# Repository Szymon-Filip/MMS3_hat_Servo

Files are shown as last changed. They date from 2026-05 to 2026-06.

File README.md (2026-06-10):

# Hat 4-kanałowy sterownik serw

## Sekcja 1: Dokumentacja Hat'a

### Krótki opis projektu
Hat to 4-kanałowy sterownik serw, bazujący na  generatorze PWM **PCA9685PW** (komunikacja I2C). Zasialnie serw jest z XT60

### Zgodność ze standardem ChainBus

* ✅ Używa złącza ChainBus, nie zmienia jego miejsca ani pinoutu.
* ✅ Używa wyłącznie interfejsów I2C, SPI lub UART i nie inicjuje samodzielnie nowych transmisji (Nie jest master'em I2C albo SPI).
* ✅ Spełnia wymagania mechaniczne standardu (wymiary PCB, rozstaw otworów).
* ✅ Pobiera maksymalny prąd zgodny z ilością na jednego hat'a
* ✅ Obsługuje napięcie wejściowe BRD_VIN do wartości 48V.

### Komunikacja i adresowanie

#### Adresacja I2C
Komunikacja z PCA9685PW odbywa się za pomocą magistrali I2C. Wszystkie linie adresowe układu PCA9685PW (A0, A1, A2, A3, A4, A5) są podłączone do napięcia 5V.

| Układ (IC) | Funkcja | Adres I2C (7-bit) |
| :--- | :--- | :---: |
| **PCA9685PW** | 16-kanałowy generator PWM 12-bit | `1111111b` (0x7F) |

---

### Przypisanie kanałów generatora PCA9685

Układ PCA9685 steruje bezpośrednio czterema wyjściami serw oraz dwoma debug diodami LED:

| Wyjście PCA9685 | Powiązany element | Typ złącza  | Opis |
| :---: | :--- | :--- | :--- |
| **LED0** | Servo 1 | **J10** | Kanał sterujący serwomechanizmu 1 |
| **LED1** | Servo 2 | **J9** | Kanał sterujący serwomechanizmu 2 |
| **LED2** | Servo 3 | **J8** | Kanał sterujący serwomechanizmu 3 |
| **LED3** | Servo 4 | **J7** | Kanał sterujący serwomechanizmu 4 |
| **LED14** | Debug LED | *Na płycie* | Dioda LED do debugowania |
| **LED15** | Debug LED | *Na płycie* | Dioda LED do debugowania |

---

### Pinout złączy serwomechanizmów (J7 – J10)

Każde złącze wyjściowe (J7, J8, J9, J10) posiada 3 piny w następującym układzie:

| Pin | Nazwa sygnału | Poziom napięcia | Opis |
| :---- | :--- | :--- | :--- |
| **1** | `GND` | 0 V | Wspólna masa układu |
| **2** | `SERVO` (PWM) | 5 V | Sygnał sterujący PWM z układu PCA9685 |
| **3** | `VCC` | `BRD_VIN` (z XT60) | Napięcie zasilające silnik serwomechanizmu |

> **⚠️ UWAGA DOTYCZĄCA BEZPIECZEŃSTWA (PINOUT):**
> Układ wyprowadzeń złączy na tym module to **[1: GND, 2: Sygnał, 3: VCC]**. Jest on odmienny od klasycznego modelarskiego standardu wtyczek serwomechanizmów (gdzie pin zasilania VCC zazwyczaj znajduje się w środku wtyku).
>
> Przed podłączeniem serwomechanizmu należy bezwzględnie zweryfikować kolejność przewodów w wiązce serwa. Błędne podłączenie może skutkować uszkodzeniem serwa lub obwodów zasilania modułu.

---

### Szczegółowy opis techniczny

#### Zasilanie serwomechanizmów (`VCC`)
Prąd zasilania serwomechanizmów nie obciąża wewnętrznych linii zasilających magistrali ChainBus. Napięcie doprowadzane jest bezpośrednio ze złącza wysokoprądowego **XT60** na pin 3 każdego złącza serwa. Zasilanie z XT-60 od razu idzie na szyne VIN ChainBus'a. Jeśli potrzebujesz zasilić serwa innym napięciem niż takim samym jak VIN ChainBus'a to odlutuj D1 (tą diode po lewej stronie do której idzie taka duża ścieżka)

#### Sterowanie sygnałem PWM
PWM jest na 5V, ale szyna I2C na 3V3 więc wszystko śmiga jak powinno

---

### Gotowe arkusze hierarchiczne
W projekcie wydzielono i zastosowano następujące arkusze hierarchiczne:
* **Servo_controller** – Schemat generatora PWM PCA9685 z konwerterem I2C 3v3 <-> 5V i zworkami do wybierania adresu I2C

---

## Sekcja 2: Specyfikacja standardu ChainBus

### Architektura i łączenie modułów
Standard ChainBus umożliwia modułowe łączenie hatów. Na jednym MMS3 można zamontować pionowo **do 8 hat'ów**. Połączenie realizowane jest poprzez wpięcie złącza męskiego kolejnego hat'a w złącze żeńskie poprzedniego.

### Komunikacja i sterowanie
Magistrala ChainBus jest w pełni cyfrowa. Płyta główna nie steruje bezpośrednio sygnałami ogólnego przeznaczenia (GPIO) na poszczególnych hat'ach. Wszelkie operacje (np. generowanie sygnałów PWM, obsługa diod) muszą być realizowane przez dedykowane układy scalone komunikujące się przez interfejsy systemowe.

Wybór aktywnego modułu realizowany jest przez układ przełącznika magistrali (bus switch) na płycie głównej. Dzięki temu linie I2C, SPI i UART są niezależne dla każdego hat'a (brak konfliktów adresów I2C między różnymi hatami).
* **Identyfikacja:** Każdy moduł powinien posiadać pamięć EEPROM na magistrali I2C w celu identyfikacji płyty przez system - układ M24C64-W skonfigurowany na adres `1010000` przy liniach adresowych A0, A1, A2 zwartych do masy.

### Zasilanie
Złącze ChainBus dostarcza następujące linie zasilania:

| Magistrala zasilania | Napięcie znamionowe | Maksymalny prąd (łączny dla 8 hatów) | Szacowany prąd na jeden hat |
| :--- | :---: | :---: | :---: |
| **5V** | 5.0 V | 1.0 A | 125 mA |
| **12V stby** | 12.0 V | 0.5 A | 65 mA |
| **BRD_VIN** | 12.0 V – 48.0 V | 1.5 A | 185 mA |

*   W przypadku zapotrzebowania na wyższą moc (jak w przypadku tego modułu sterowania serwami), stosuje się dodatkowe złącze zasilania XT60 (obciążalność do ok. 60 A).

---

## Sekcja 3: Licencja, linki i tagi

### Licencjonowanie projektu

*   **PCB:** [CERN-OHL-W](https://ohwr.org/project/cernohl/wikis/Documents/CERN-OHL-version-2) - Umożliwia modyfikacje i sprzedaż pod warunkiem zachowania informacji o oryginalnym autorze. Zmiany muszą być open source.
*   **Software:** [MIT License](https://opensource.org/licenses/MIT) - Umożliwia modyfikacje i sprzedaż komercyjną pod warunkiem zachowania informacji o autorze (zmiany nie muszą być udostępniane jako open source).

### Tagi projektu
#chainbus #MMS3 #ModuCard

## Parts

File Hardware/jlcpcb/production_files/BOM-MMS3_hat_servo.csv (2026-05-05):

Comment | Designator | Footprint | LCSC | Quantity
100nF | C1,C2,C30 | C_0603 | C14663 | 3
10kΩ | R12,R19,R2,R20,R21,R22,R28,R29,R3,R30,R31,R32,R33,R6,R7,R8,R9 | R_0402 | C25744 | 17
10uF | C16,C18,C29 | C_0603 | C19702 | 3
330Ω | R1 | R_0402 | C25104 | 1
510Ω | R10,R11 | R_0402 | C25123 | 2
AMS1117 | U4 | SOT-223-3_L6.5-W3.4-P2.30-LS7.0-BR | C6186 | 1
AO3400A | Q4,Q5 | Q_SOT-23 | C20917 | 2
M24C64 | U2 | SOIC-8_L5.0-W4.0-P1.27-LS6.0-BL | C79988 | 1
M7 | D1 | D_SMA | C95872 | 1
PCA9685PW,118 | U1 | TSSOP-28_L9.7-W4.4-P0.65-LS6.4-TL | C2678753 | 1
Red | D5,D6,D7 | D_0603 | C2286 | 3
SN74CB3Q3245PWR | U3 | TSSOP-20_L6.5-W4.4-P0.65-LS6.4-BL | C470961 | 1
Conn_01x03 | J10 | JST_XH_S3B-XH-A_1x03_P2.50mm_Horizontal |  | 1
Conn_01x03 | J7 | JST_XH_S3B-XH-A_1x03_P2.50mm_Horizontal |  | 1
Chainbus Out | J2 | PinSocket_2x16_P2.54mm_Vertical_SMD |  | 1
Conn_01x03 | J9 | JST_XH_S3B-XH-A_1x03_P2.50mm_Horizontal |  | 1
Conn_01x04_Pin | J3 | PinHeader_1x04_P2.54mm_Vertical |  | 1
Conn_01x03 | J8 | JST_XH_S3B-XH-A_1x03_P2.50mm_Horizontal |  | 1
Chainbus in | J1 | PinHeader_2x16_P2.54mm_Vertical_SMD |  | 1

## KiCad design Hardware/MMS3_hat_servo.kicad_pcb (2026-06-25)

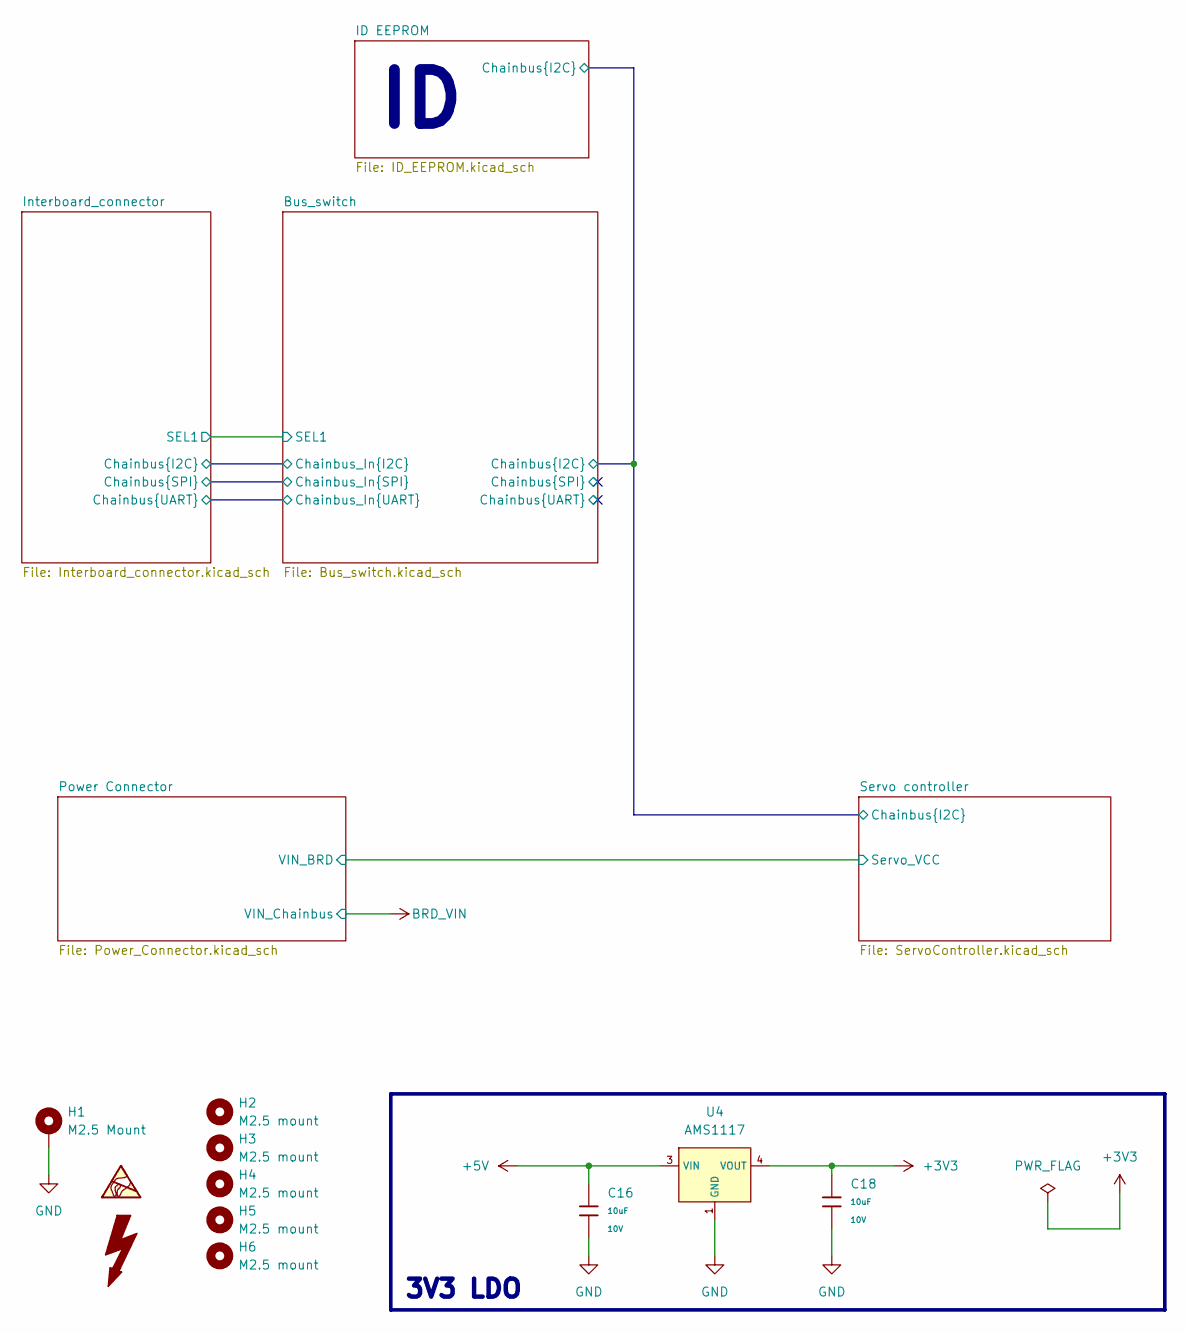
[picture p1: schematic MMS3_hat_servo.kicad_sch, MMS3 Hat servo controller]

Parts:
C16, C18: 10uF; C_0603; Voltage Rated 10V; Tolerance ±10%; Part CL10A106KP8NNNC; LCSC C19702
H1: M2.5 Mount; MountingHole_2.7mm_M2.5_DIN965_Pad_TopOnly
H2, H3, H4, H5, H6: M2.5 mount; MountingHole_2.7mm_M2.5
U4: AMS1117; SOT-223-3_L6.5-W3.4-P2.30-LS7.0-BR; Output Voltage 3.3V; Dropout Voltage 1.3V@(800mA); Part AMS1117-3.3; LCSC C6186

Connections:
+3V3: C18.1, U4.2 (VOUT), U4.4 (VOUT); also elsewhere on the board
+5V: C16.1, U4.3 (VIN); also elsewhere on the board
GND: C16.2, C18.2, H1.1 (1_1), U4.1 (GND); also elsewhere on the board

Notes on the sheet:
3V3 LDO

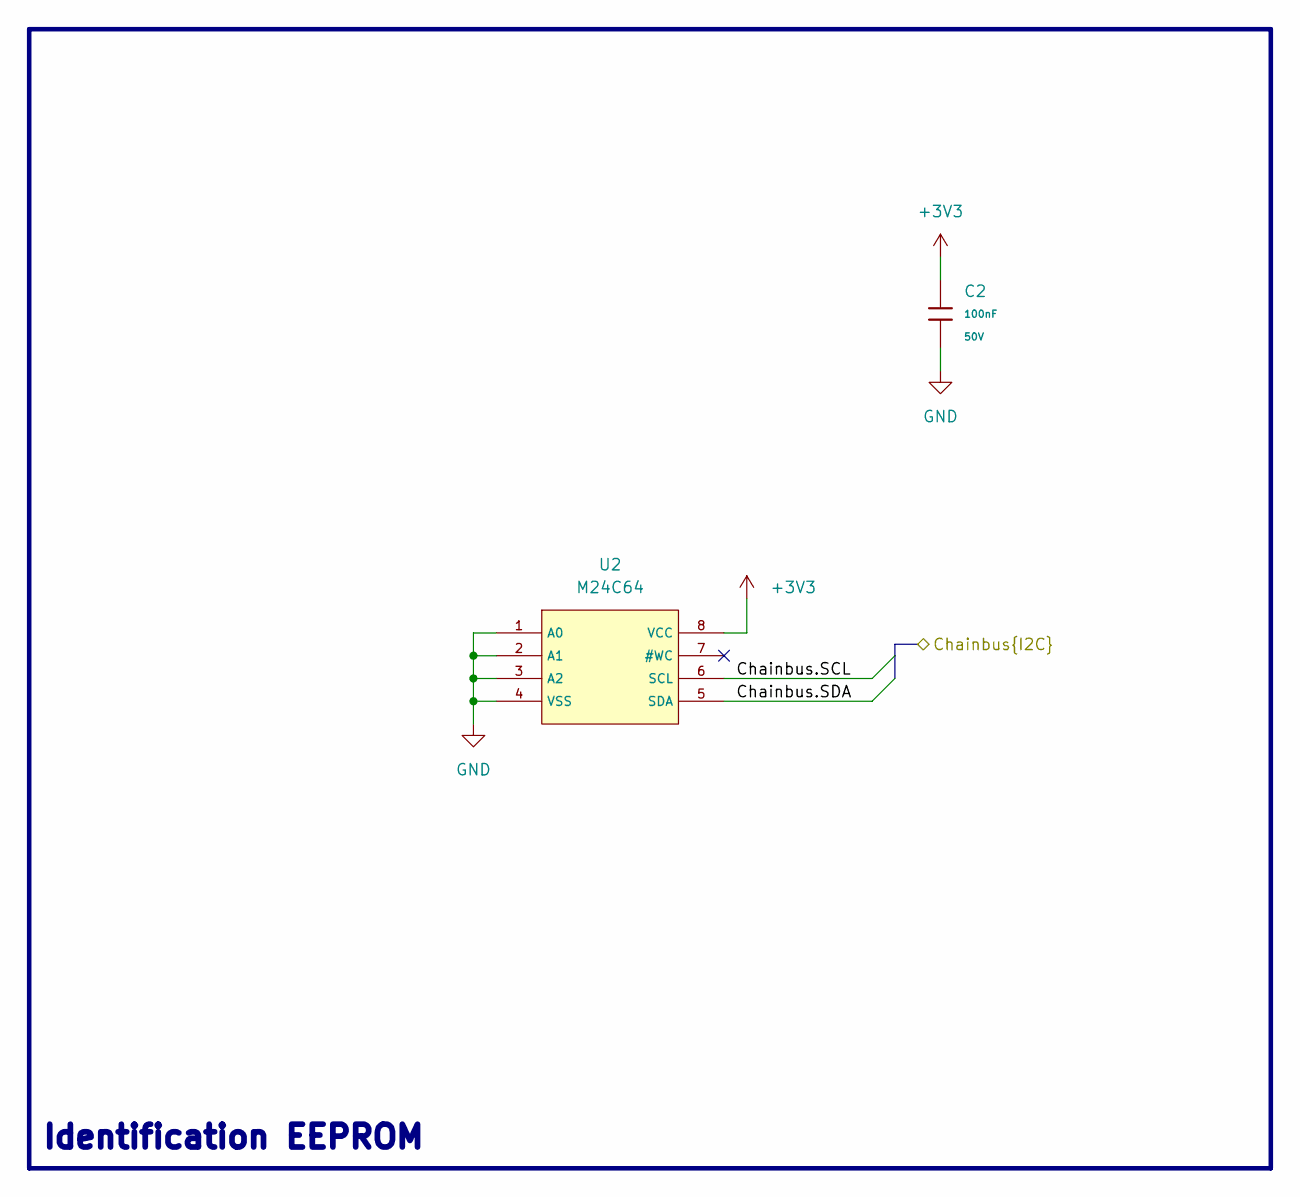
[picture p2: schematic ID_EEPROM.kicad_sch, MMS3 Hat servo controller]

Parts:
C2: 100nF; C_0603; Voltage Rated 50V; Tolerance ±10%; Part CC0603KRX7R9BB104; LCSC C14663
U2: M24C64; SOIC-8_L5.0-W4.0-P1.27-LS6.0-BL; Supply Voltage 1.8V~5.5V; Part M24C64-RMN6TP; LCSC C79988

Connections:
+3V3: C2.1, U2.8 (VCC); also elsewhere on the board
/Bus_switch/Chainbus.SCL: U2.6 (SCL); also elsewhere on the board
/Bus_switch/Chainbus.SDA: U2.5 (SDA); also elsewhere on the board
GND: C2.2, U2.1 (A0), U2.2 (A1), U2.3 (A2), U2.4 (VSS); also elsewhere on the board

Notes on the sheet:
Identification EEPROM

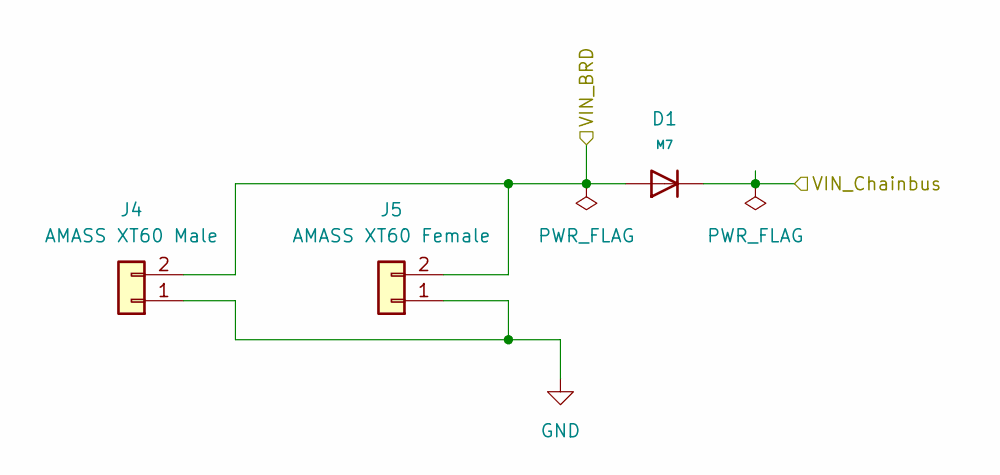
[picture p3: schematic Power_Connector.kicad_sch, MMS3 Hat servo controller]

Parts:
D1: M7; D_SMA; Forward Voltage (Vf@If) 1.1V@1A; Reverse Voltage (Vr) 1kV; Part M7; LCSC C95872
J4: AMASS XT60 Male; AMASS_XT60PW-M_1x02_P7.20mm_Horizontal; LCSC C98732
J5: AMASS XT60 Female; AMASS_XT60PW-F_1x02_P7.20mm_Horizontal; LCSC C428722

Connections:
/Power Connector/VIN_BRD: D1.2, J4.2, J5.2; also elsewhere on the board
BRD_VIN: D1.1; also elsewhere on the board
GND: J4.1, J5.1; also elsewhere on the board

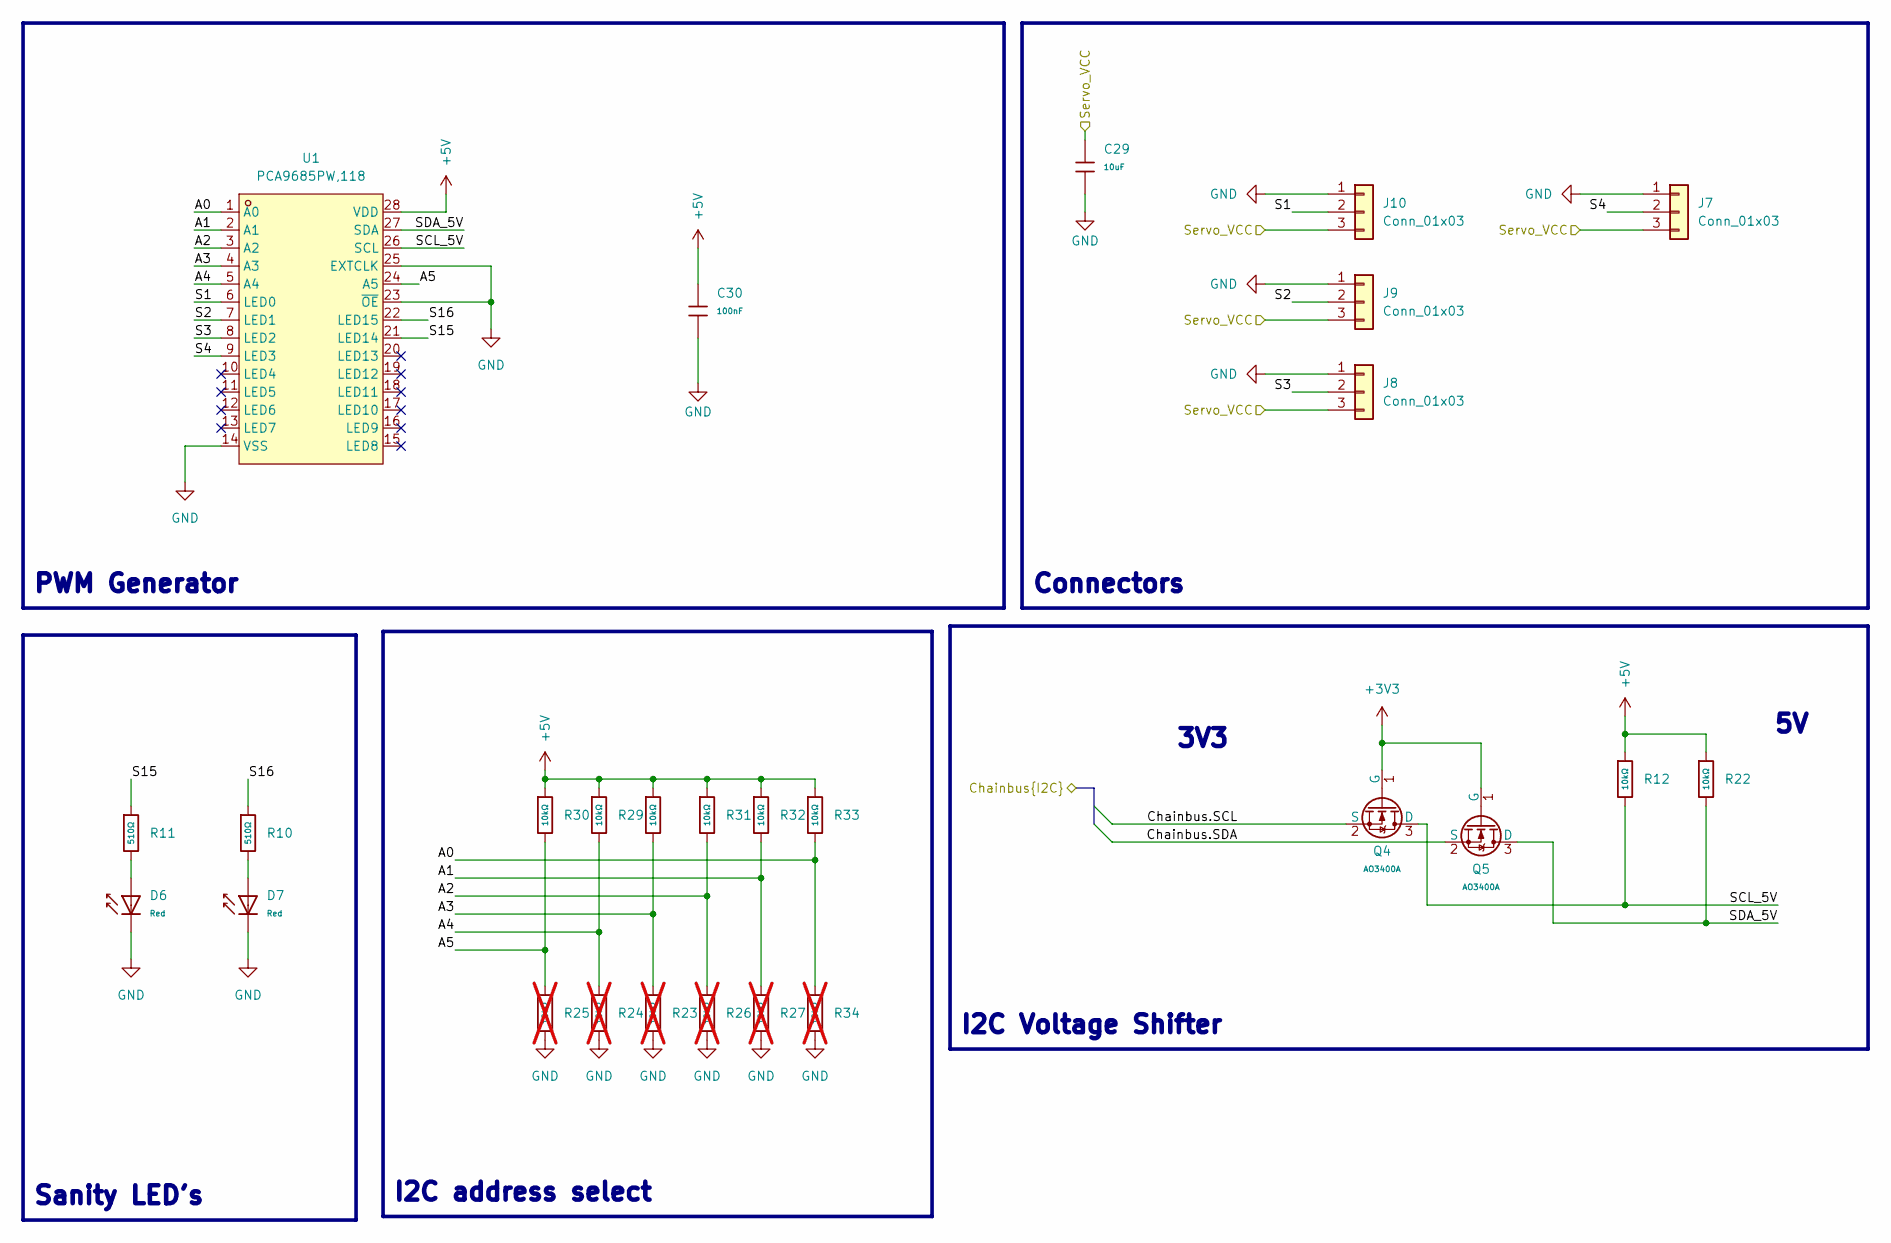
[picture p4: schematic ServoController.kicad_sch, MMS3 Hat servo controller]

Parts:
C29: 10uF; C_0603; Voltage Rated 10V; Tolerance ±10%; Part CL10A106KP8NNNC; LCSC C19702
C30: 100nF; C_0603; Voltage Rated 50V; Tolerance ±10%; Part CC0603KRX7R9BB104; LCSC C14663
D6, D7: Red; D_0603; Part KT-0603R; LCSC C2286
J7, J8, J9, J10: Conn_01x03; JST_XH_S3B-XH-A_1x03_P2.50mm_Horizontal
Q4, Q5: AO3400A; Q_SOT-23; Part AO3400A; LCSC C20917
R10, R11: 510Ω; R_0402; Overload Voltage (Max) 50V; Tolerance ±1%; Part 0402WGF5100TCE; LCSC C25123
R12, R22, R28, R29, R30, R31, R32, R33: 10kΩ; R_0402; Overload Voltage (Max) 50V; Tolerance ±1%; Part 0402WGF1002TCE; LCSC C25744
R23, R24, R25, R26, R27, R34: 10kΩ; R_0402; Overload Voltage (Max) 50V; Tolerance ±1%; Part 0402WGF1002TCE; LCSC C25744; not fitted
U1: PCA9685PW,118; TSSOP-28_L9.7-W4.4-P0.65-LS6.4-TL; MPN PCA9685PW,118; LCSC Part C2678753

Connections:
+3V3: Q4.1 (G), Q5.1 (G); also elsewhere on the board
+5V: C30.1, R12.1, R22.1, R28.1, R29.1, R30.1, R31.1, R32.1, R33.1, U1.28 (VDD); also elsewhere on the board
/Bus_switch/Chainbus.SCL: Q4.2 (S); also elsewhere on the board
/Bus_switch/Chainbus.SDA: Q5.2 (S); also elsewhere on the board
/Power Connector/VIN_BRD: C29.1, J7.3, J8.3, J9.3, J10.3; also elsewhere on the board
/Servo controller/A0: R33.2, R34.1, U1.1 (A0)
/Servo controller/A1: R27.1, R32.2, U1.2 (A1)
/Servo controller/A2: R26.1, R31.2, U1.3 (A2)
/Servo controller/A3: R23.1, R28.2, U1.4 (A3)
/Servo controller/A4: R24.1, R29.2, U1.5 (A4)
/Servo controller/A5: R25.1, R30.2, U1.24 (A5)
/Servo controller/S1: J10.2, U1.6 (LED0)
/Servo controller/S2: J9.2, U1.7 (LED1)
/Servo controller/S3: J8.2, U1.8 (LED2)
/Servo controller/S4: J7.2, U1.9 (LED3)
/Servo controller/S15: R11.1, U1.21 (LED14)
/Servo controller/S16: R10.1, U1.22 (LED15)
/Servo controller/SCL_5V: Q4.3 (D), R12.2, U1.26 (SCL)
/Servo controller/SDA_5V: Q5.3 (D), R22.2, U1.27 (SDA)
GND: C29.2, C30.2, D6.1, D7.1, J7.1, J8.1, J9.1, J10.1, R23.2, R24.2, R25.2, R26.2, R27.2, R34.2, U1.14 (VSS), U1.23 (~OE), U1.25 (EXTCLK); also elsewhere on the board
unnamed: D6.2, R11.2
unnamed: D7.2, R10.2

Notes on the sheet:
Sanity LED's
Connectors
I2C Voltage Shifter
PWM Generator
3V3
I2C address select

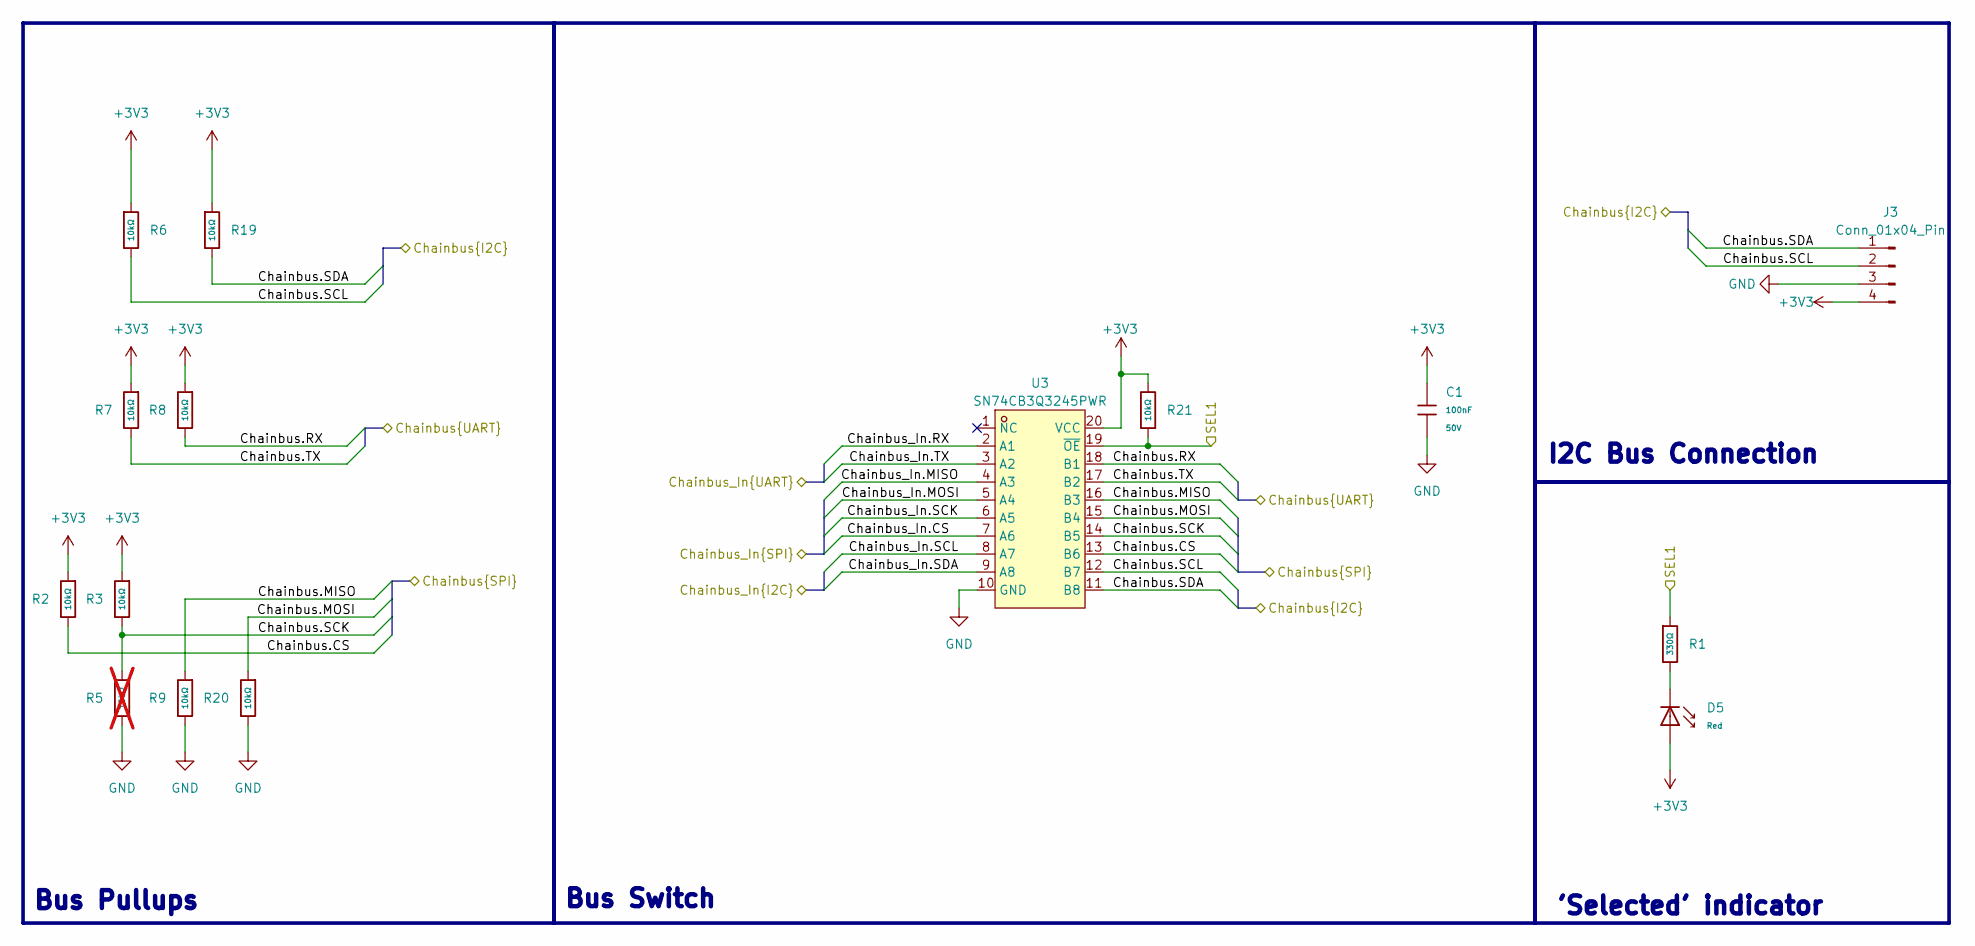
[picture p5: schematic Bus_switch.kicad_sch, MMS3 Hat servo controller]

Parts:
C1: 100nF; C_0603; Voltage Rated 50V; Tolerance ±10%; Part CC0603KRX7R9BB104; LCSC C14663
D5: Red; D_0603; Part KT-0603R; LCSC C2286
J3: Conn_01x04_Pin; PinHeader_1x04_P2.54mm_Vertical
R1: 330Ω; R_0402; Overload Voltage (Max) 50V; Tolerance ±1%; Part 0402WGF3300TCE; LCSC C25104
R2, R3, R6, R7, R8, R9, R19, R20, R21: 10kΩ; R_0402; Overload Voltage (Max) 50V; Tolerance ±1%; Part 0402WGF1002TCE; LCSC C25744
R5: 10kΩ; R_0402; Overload Voltage (Max) 50V; Tolerance ±1%; Part 0402WGF1002TCE; LCSC C25744; not fitted
U3: SN74CB3Q3245PWR; TSSOP-20_L6.5-W4.4-P0.65-LS6.4-BL; MPN SN74CB3Q3245PWR; LCSC Part C470961

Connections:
+3V3: C1.1, D5.2, J3.4, R2.1, R3.1, R6.1, R7.1, R8.1, R19.1, R21.2, U3.20 (VCC); also elsewhere on the board
/Bus_switch/Chainbus.CS: R2.2, U3.13 (B6)
/Bus_switch/Chainbus.MISO: R9.1, U3.16 (B3)
/Bus_switch/Chainbus.MOSI: R20.1, U3.15 (B4)
/Bus_switch/Chainbus.RX: R8.2, U3.18 (B1)
/Bus_switch/Chainbus.SCK: R3.2, R5.1, U3.14 (B5)
/Bus_switch/Chainbus.SCL: J3.2, R6.2, U3.12 (B7); also elsewhere on the board
/Bus_switch/Chainbus.SDA: J3.1, R19.2, U3.11 (B8); also elsewhere on the board
/Bus_switch/Chainbus.TX: R7.2, U3.17 (B2)
/Bus_switch/Chainbus_In.CS: U3.7 (A6); also elsewhere on the board
/Bus_switch/Chainbus_In.MISO: U3.4 (A3); also elsewhere on the board
/Bus_switch/Chainbus_In.MOSI: U3.5 (A4); also elsewhere on the board
/Bus_switch/Chainbus_In.RX: U3.2 (A1); also elsewhere on the board
/Bus_switch/Chainbus_In.SCK: U3.6 (A5); also elsewhere on the board
/Bus_switch/Chainbus_In.SCL: U3.8 (A7); also elsewhere on the board
/Bus_switch/Chainbus_In.SDA: U3.9 (A8); also elsewhere on the board
/Bus_switch/Chainbus_In.TX: U3.3 (A2); also elsewhere on the board
/Bus_switch/SEL1: R1.1, R21.1, U3.19 (~OE); also elsewhere on the board
GND: C1.2, J3.3, R5.2, R9.2, R20.2, U3.10 (GND); also elsewhere on the board
unnamed: D5.1, R1.2

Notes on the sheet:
'Selected' indicator
Bus Switch
I2C Bus Connection
Bus Pullups

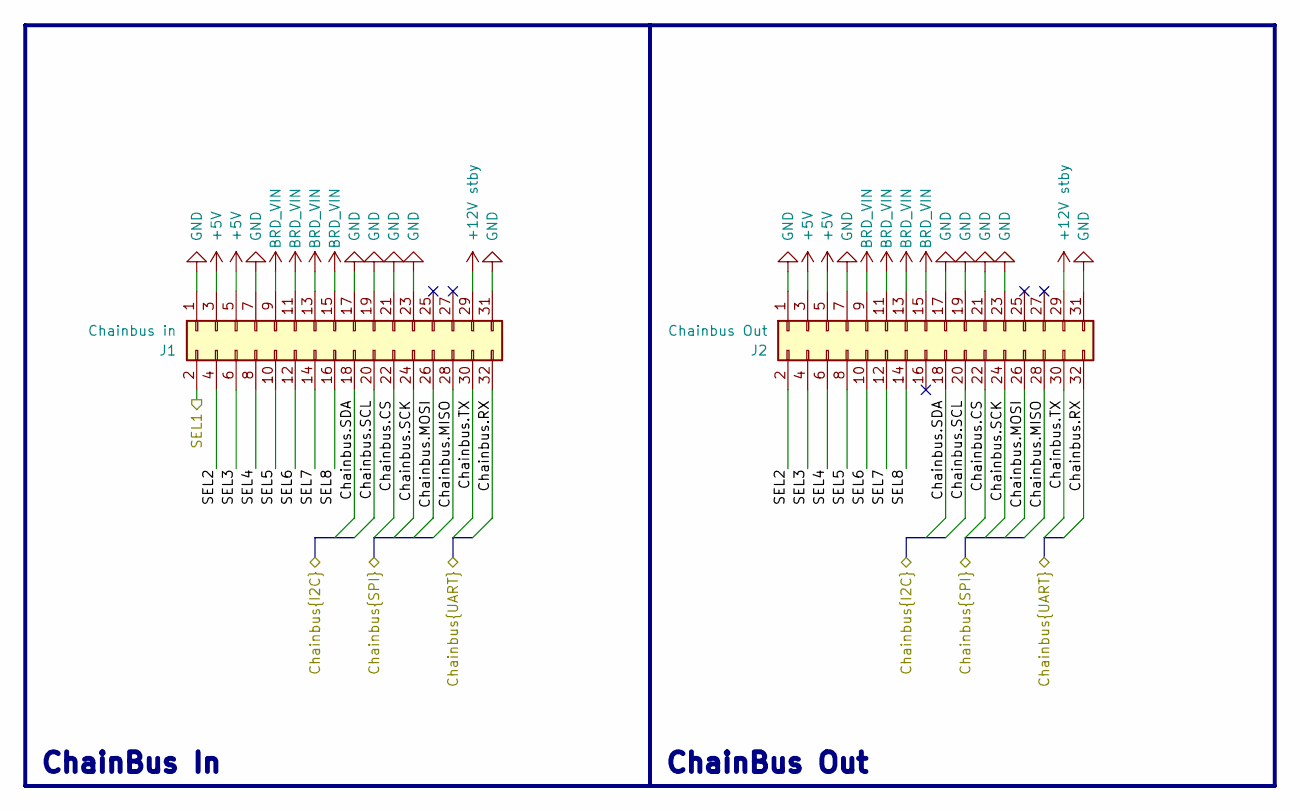
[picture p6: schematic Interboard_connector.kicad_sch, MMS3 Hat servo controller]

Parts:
J1: Chainbus in; PinHeader_2x16_P2.54mm_Vertical_SMD
J2: Chainbus Out; PinSocket_2x16_P2.54mm_Vertical_SMD

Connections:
+5V: J1.3, J1.5, J2.3, J2.5; also elsewhere on the board
+12V stby: J1.29, J2.29
/Bus_switch/Chainbus_In.CS: J1.22, J2.22; also elsewhere on the board
/Bus_switch/Chainbus_In.MISO: J1.28, J2.28; also elsewhere on the board
/Bus_switch/Chainbus_In.MOSI: J1.26, J2.26; also elsewhere on the board
/Bus_switch/Chainbus_In.RX: J1.32, J2.32; also elsewhere on the board
/Bus_switch/Chainbus_In.SCK: J1.24, J2.24; also elsewhere on the board
/Bus_switch/Chainbus_In.SCL: J1.20, J2.20; also elsewhere on the board
/Bus_switch/Chainbus_In.SDA: J1.18, J2.18; also elsewhere on the board
/Bus_switch/Chainbus_In.TX: J1.30, J2.30; also elsewhere on the board
/Bus_switch/SEL1: J1.2; also elsewhere on the board
/Interboard_connector/SEL2: J1.4, J2.2
/Interboard_connector/SEL3: J1.6, J2.4
/Interboard_connector/SEL4: J1.8, J2.6
/Interboard_connector/SEL5: J1.10, J2.8
/Interboard_connector/SEL6: J1.12, J2.10
/Interboard_connector/SEL7: J1.14, J2.12
/Interboard_connector/SEL8: J1.16, J2.14
BRD_VIN: J1.9, J1.11, J1.13, J1.15, J2.9, J2.11, J2.13, J2.15; also elsewhere on the board
GND: J1.1, J1.7, J1.17, J1.19, J1.21, J1.23, J1.31, J2.1, J2.7, J2.17, J2.19, J2.21, J2.23, J2.31; also elsewhere on the board

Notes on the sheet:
ChainBus Out
ChainBus In

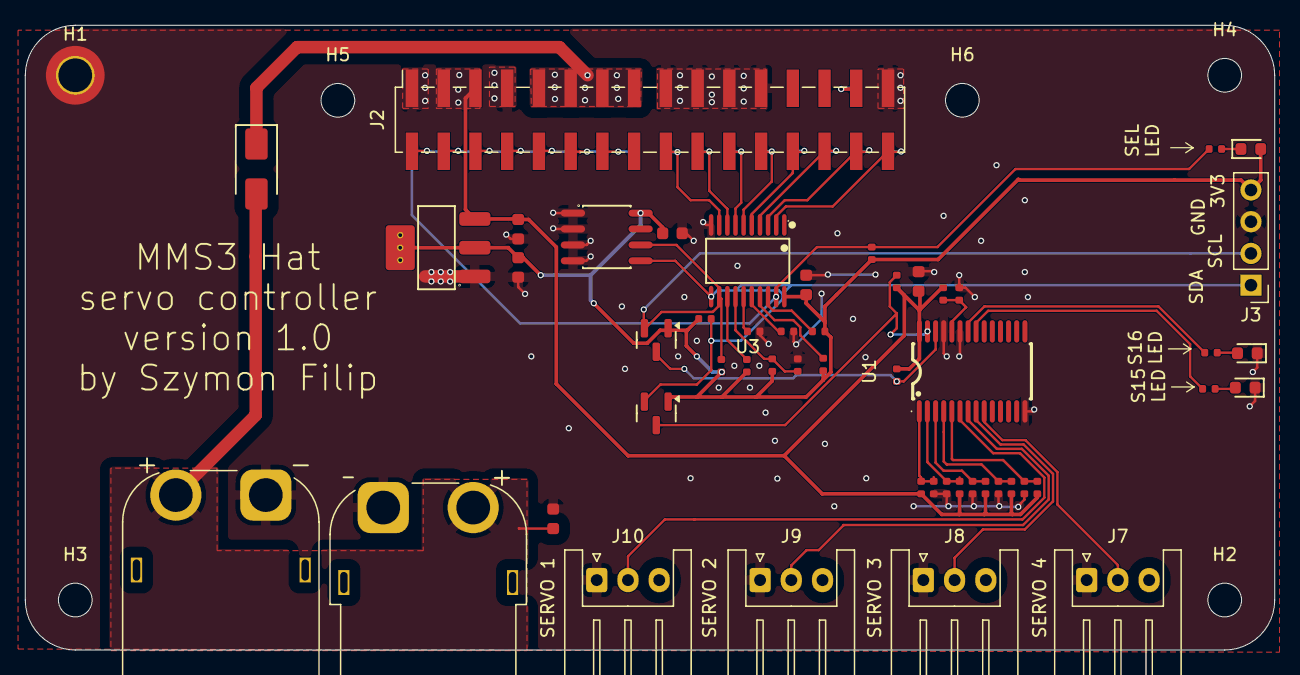
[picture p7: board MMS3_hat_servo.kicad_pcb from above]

Board: 2 copper layers, 100.0 x 50.0 mm, 58 parts (1 on the bottom side), 47 nets.

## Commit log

2026-04-08 updated Bus switch to one stocked by TME
    [Bus_switch.kicad_sch, MMS3_hat_templates.kicad_pcb]
2026-04-21 ServoController
    Dodano arkusz sterownika servo, aktualizacja polaczen
    [Bus_switch.kicad_sch, ID_EEPROM.kicad_sch, Interboard_connector.kicad_sch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]
2026-04-21 Add servo controller details to README
2026-04-27 polished the schemtic
    [Bus_switch.kicad_sch, Interboard_connector.kicad_sch, MMS3_hat_templates.kicad_sch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]
2026-04-27 updated PCB to up-to-date template:
    [MMS3_hat_templates.kicad_pcb]
2026-04-28 added 5V i2c shifter
    [MMS3_hat_templates.kicad_sch, ServoController.kicad_sch]
2026-04-29 PCB design
    In progress
    [Bus_switch.kicad_sch, ID_EEPROM.kicad_sch, Interboard_connector.kicad_sch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]
2026-05-03 PCB design
    Adjustments
    [MMS3_hat_servo.kicad_pcb]
2026-05-03 Revieved by Wojtek
    [Bus_switch.kicad_sch, ID_EEPROM.kicad_sch, Interboard_connector.kicad_sch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]
2026-05-05 change mosfets to basic assembly
    [BOM-MMS3_hat_servo.csv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]
2026-06-10 added documentation
    [BOM-MMS3_hat_servo.csv, Bus_switch.kicad_sch, ID_EEPROM.kicad_sch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]
2026-06-25 generated gerber
    [CPL-MMS3_hat_servo.csv, MMS3_hat_servo-CuBottom.gbr, MMS3_hat_servo-CuTop.gbr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]
